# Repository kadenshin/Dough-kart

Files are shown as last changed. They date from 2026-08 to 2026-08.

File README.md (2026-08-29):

# Dough-kart


An easy-to-build, weldless drifting single-occupant electric go kart.\
I started this project on 7/22/2026. I just wanted to build something fun before I go off to college. I'm adding more features to this project as I think of them.
The design of the kart was heavily inspired from Razor's Crazy Cart XL.

## Design brief
- One rider 
- Rider height: 5’9 - 5’10, weight 140-160lb
- Electric powered 
  - Single powered wheel in the center-middle of kart
- Target top speed: ~ 20 mph
- Intended surface: pavement, concrete
  - Smooth surfaces only, little suspension
- Drift/drive method: two swivel caster wheels in the back and one steerable powered wheel near front always contacting ground
  - The casters' axis of rotation are able to be adjusted relative to the ground, which allows the rider to adjust level of "driftyness"
    - Caster wheels axis of rotation more oblique to the ground = more control 
    - Caster wheels axis of rotation perpendicular to the ground = Tokyo drift
- Maximum overall width and length: roughly 110cm x 70cm x 50cm
- Fabrication tools: soldering iron(optional), 3D printer, hacksaw, hand drill
- Estimated cost: ~$600 (half the price of the Razor Crazy Cart XL)

## Assembly
- The entire vehicle is weldless; everything is secured together with aluminum gussets and M8 bolts and nuts.
- There are jigs in the CAD folder to help with drilling accurate holes.  



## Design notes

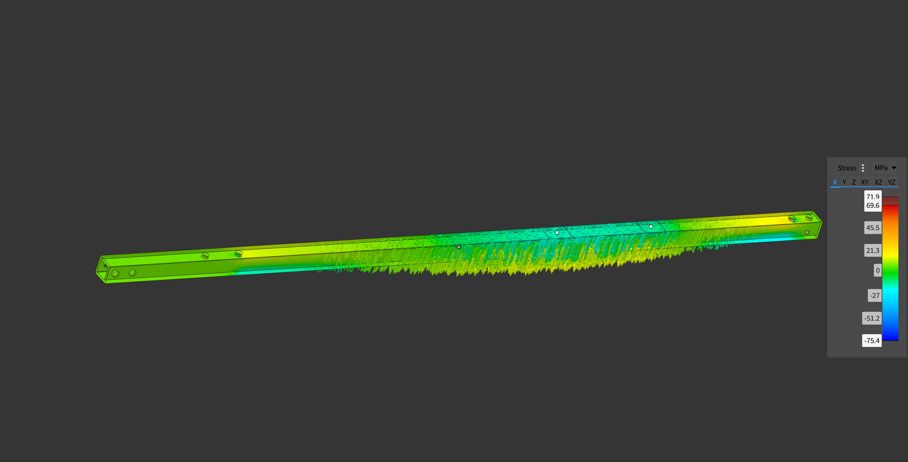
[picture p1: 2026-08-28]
assets/FrameFEA.png

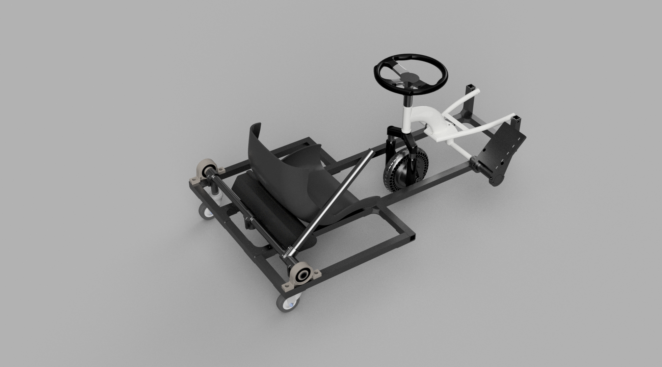
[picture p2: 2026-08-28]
assets/KartRENDER.png

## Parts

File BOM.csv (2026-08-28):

Item Name | Qty | Price (total) (USD) | Item link | Notes
Front Suspension Fork, 10 inch Shock Absorption Parts Anti Vibration Hydraulic Shock Absorber | 1 | $39.49 | Electric Scooter Front Suspension Fork, 10 inch Shock Absorption Parts Anti Vibration Hydraulic Shock Absorber | Suspension will hopefully dampen vibration (one of the biggest cons of a hub motor wheel)
Zip Ties 8 inch (100 Pack) | 100 | $3.99 | Zip Ties 8 inch (100 Pack), 40lbs Tensile Strength, Black Cable Ties, Wire Ties for indoor and outdoor use, by Skalon | Used for securing battery/electronics to frame
7/8" Inner Wide Round U Bolts | 2 | $8.19 | uxcell 7/8" Inner Wide Round U Bolts 2" Length 304 Stainless 2 Set | To secure the handlebar/footrest to the frame
Center punch | 2 | $5.68 | 2PCS Automatic Center Punch,5'' Spring Loaded Center Punch, Heavy Duty Steel Adjustable Center Marker Punch Tool with 2PCS Extra Replacement Tip for Metal,Plastic,Wood,Glass by YUIOASE | Essential for making accurate holes with a hand drill (I'm using jigs to align the center punch on the aluminum)
Polyureuthane Caster wheels | 4 | $12.98 | Caster Wheels with Threaded Stem, 3 Inch Locking Swivel Casters Set of 4 | For back wheels
Blue loctite/threadlocker | 1 | $7.49 | ThreadLocker Blue, Thread Lock Medium Strength Lock Tight for Nuts, Bolts, Fasteners and Metals, Anaerobic Curing Metal Glue to Prevent Loosening and Corrosion (M243-50ml) | For use on most bolts, there will be tons of vibration so threadlocker is needed to prevent loosening
M6 screw set | 1 | $9.99 | Fgruh 185PCS M6 Socket Screws Assortment Kit, M6x8/10/12/16/20/25/30/35 mm | For use on the pedal collars and screwing stuff onto the frame
3/8'-16 heatset inserts | 10 | $9.99 | ruthex 3/8"-16 Threaded Inserts - 15 Pieces RX-3/8“-16-x12.7 Brass Heat Set Insert for Plastic Parts - Inches UNC knurled Nuts - Insert by Heat into 3D Printing Components | For attaching the casters to the drifting assembly through the 3d printed adapter
1" pillow bearings | 2 | $15.79 | 2 Pack UCP205-16 Pillow Block Mounted Ball Bearing - 1" Bore - Solid Cast Iron Base - Self Aligning | For mounting the main back tube onto the frame
8in 36V 500W motor + controller + throttle | 1 | $139.90 | 8in Hub Motor Kit 36V 500W Brushless Gearless with 25A BLDC Controller | Very convenient as it comes with a controller and throttle
Li-ion 36v 10Ah battery | 1 | $0.00 |  | Already own an old one
Plexiglass sheets | 2 | $6.99 | 8×10" Plexiglass Sheets 1/8 inch Thick,3mm Clear Acrylic Sheet 2 Pack | Something for the electronics to sit on
XT60 connectors | 3 | $8.99 | Yeebline 3 Pairs (6PCS) XT60 Plug Female and Male Connector, XT60 Connector Plug Adapter with 100mm 12AWG Silicone Copper Wire Cable Cord for RC Lipo Battery Cable Drone | For connecting the battery to the motor controller
5 pin battery connector | 1 | $9.99 | KH866 E-Bike Battery Power Discharge Connector – Compatible with Hailong 5 Pin Connector Pair Male & Female Plug for Ebikes Battery, Cycling Parts, Black & Silver | For connecting the battery to the XT60 connector (need to solder)
Aluminum plates | 3 | $9.49 | PATIKIL 6061 T651 Aluminum Sheet Metal 6 x 8 x 1/25.4(0.04") Inch 3Pcs Flat Plain Aluminum Plate Covered Stock with Protective Film, Heat Rectangle 1MM for Lndustry Crafting | For shear panels to prevent the frame from racking
Foam tape | 1 | $5.35 | Frost King R734H Sponge Rubber Foam Tape 3/4" W X 7/16" H X 10' L, Black | To dampen the vibrations/impacts on the seat and the drift mechanism
1" pitch aluminum gussets | 18 | $74.09 | 1/2 in. Pitch Gussets — AndyMark | For securing the frame together
6061-T6 Aluminum tubes and 6063-T52square tubes | 15 | $158.24 | Speedy Metals 1" SQ x 3/4" ID x .125" Wall 6063 Aluminum Square Tube, https://www.speedymetals.com/pc-4590-8371-1-od-x-125-wall-tube-6061-t6-aluminum.aspx | For the frame, drift mechanism and drift lever.
Aluminum Slip-on Fitting(single socket tee | 4 | $38.64 | Aluminum Slip-on Fitting, Tee Through-Hole Connector for 1" Rail OD | McMaster-Carr | Single socket tees for attaching casters, drift lever and hardstop to the back tube. | NOTE: Shipping+taxes added to this part and below (classic McmasterCarr)
Tube-Connecting Nut (star nuts) | 5 | $14.24 | Tube-Connecting Nut, for 1.120" - 1.150" Tube ID, 3/8"-16 Thread Size | McMaster-Carr | For attaching the handlebar/footrest to the scooter headtube piece
M8 40mm socket screws | 50 | $20.26 | Black-Oxide Alloy Steel Socket Head Screw, M8 x 1.25 mm Thread Size, 40 mm Long, Partially Threaded | McMaster-Carr | For securing the frame together
M8 locknuts | 50 | $17.60 | High-Strength Steel Nylon-Insert Locknut, Zinc Plated, M8 x 1.25 mm Thread Size | McMaster-Carr | For securing the frame together
3/8"-16 bolts, washers, nuts | 10 | $14.53 | Grade 5 Steel Hex Head Screws with Nuts and Washers, Medium-Strength, 3/8"-16 Thread Size, 2" Long | McMaster-Carr | For securing the scooter headtube to the star nut
Total Price (USD): | $631.92

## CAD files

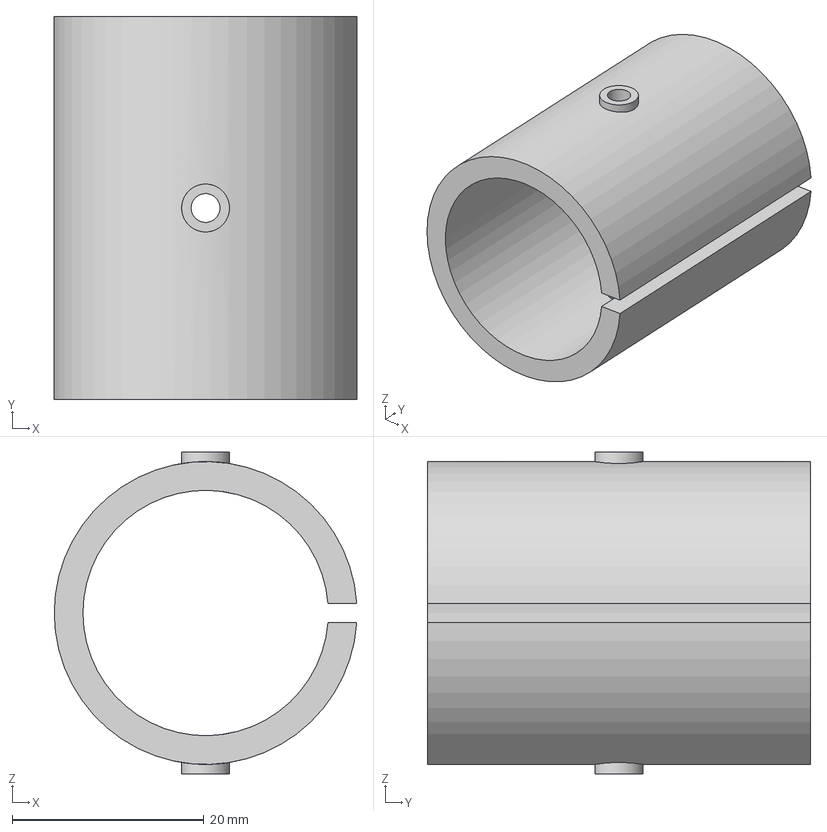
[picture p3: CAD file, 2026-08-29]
cad/Jig for round tubing.step
31.6 x 40.0 x 33.6 mm

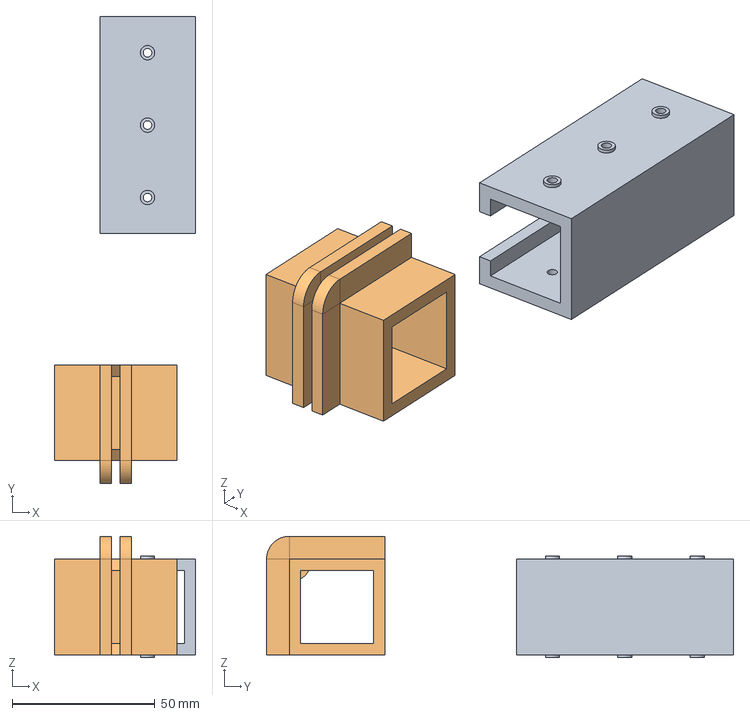
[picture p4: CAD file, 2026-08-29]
cad/Jigs for Sq. tubing.step
49.6 x 163.8 x 42.6 mm

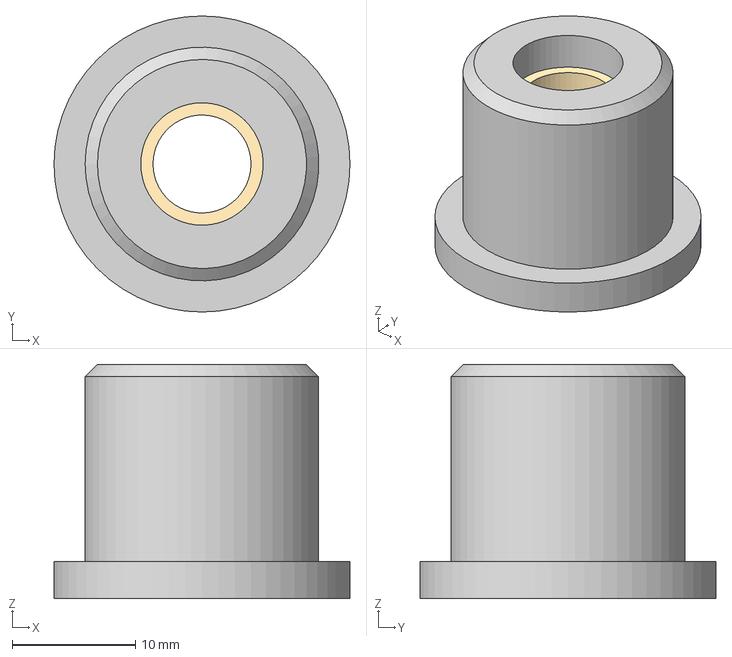
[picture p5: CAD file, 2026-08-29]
cad/3DP Insert for stem casters.step
24.0 x 24.0 x 19.0 mm

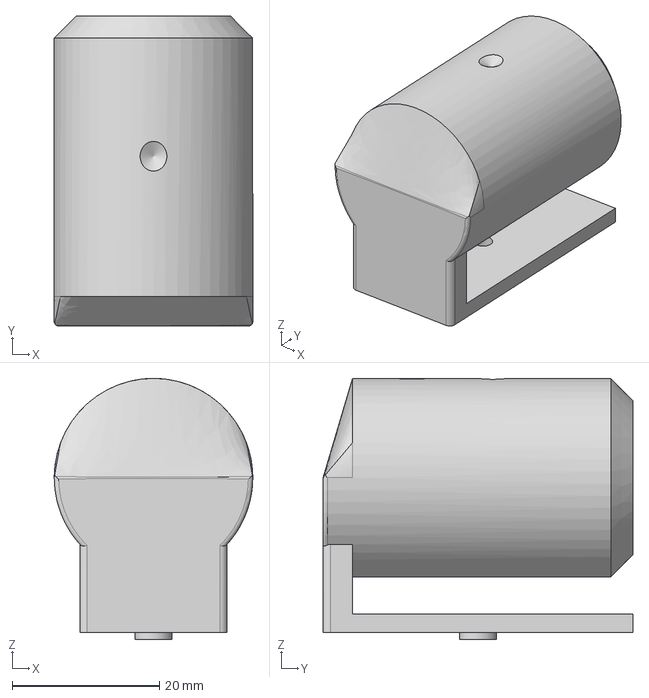
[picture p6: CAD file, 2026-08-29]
cad/Jig for SST.step
27.0 x 42.1 x 35.5 mm

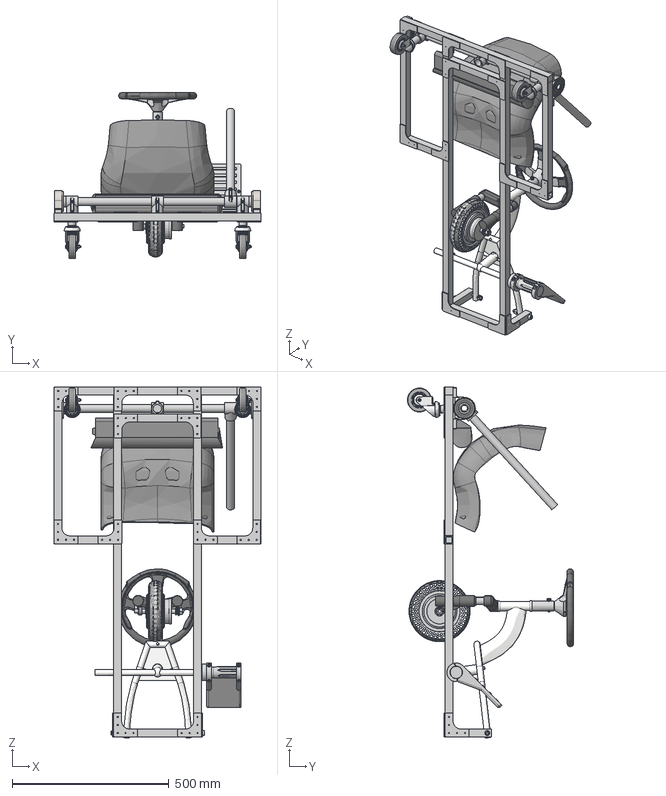
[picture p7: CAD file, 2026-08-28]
cad/KartFINAL.step
660.7 x 530.2 x 1120.4 mm
92217A617_18-8 Stainless Steel ASME Washer x 10
HFN ASME B18.2.4.4M - M14 x 2 Steel Grade 2H Plain x 2
ISO 4762 - M10 x 70 Steel 4.6 Plain
ISO 4762 - M10 x 70 Steel 4.6 Plain_1
ISO 10512 - M10 x 1.25 Steel 6 Plain x 2
ISO 10673-S-10 Steel 100 HV Plain x 3
94290A581_Tube-Connecting Nut
HSHCS ASME B18.3 - 1/4-20 UNC x 1 Steel Grade 2 Plain

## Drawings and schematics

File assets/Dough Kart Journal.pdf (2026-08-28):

# Dough Kurt

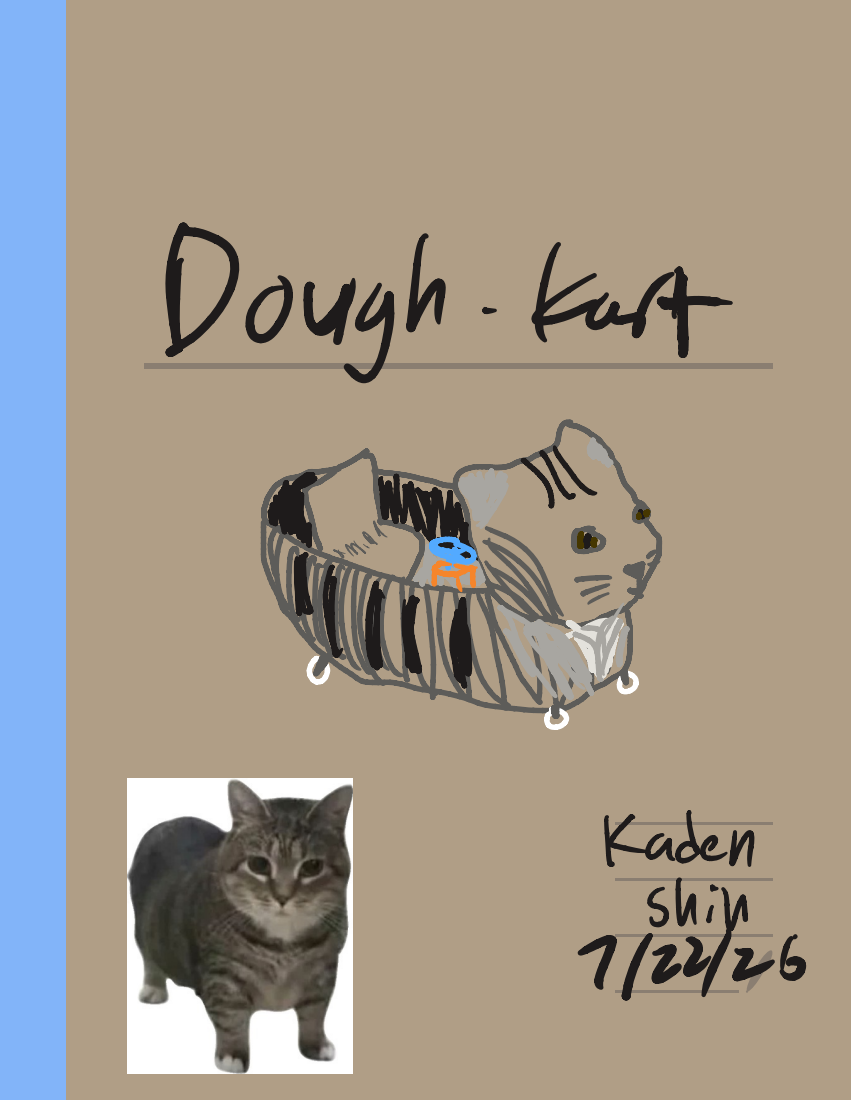
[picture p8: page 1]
Kaden Shill 1/22/26

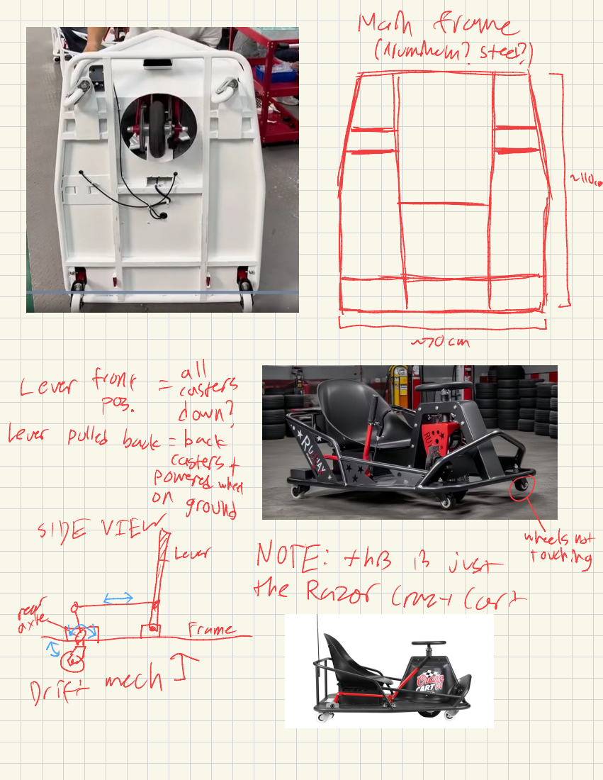
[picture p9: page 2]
Mach; frame; Lever; from e; -insters; POS.; down?; pulled back; = back; pastee; ground,; SIDE VIEW; heals; not; ame; NOTE:; thB; just; touching; the; Razor; Crust Cort; mech ⁻; Drift

## Potential add-ons:

## Timeline :

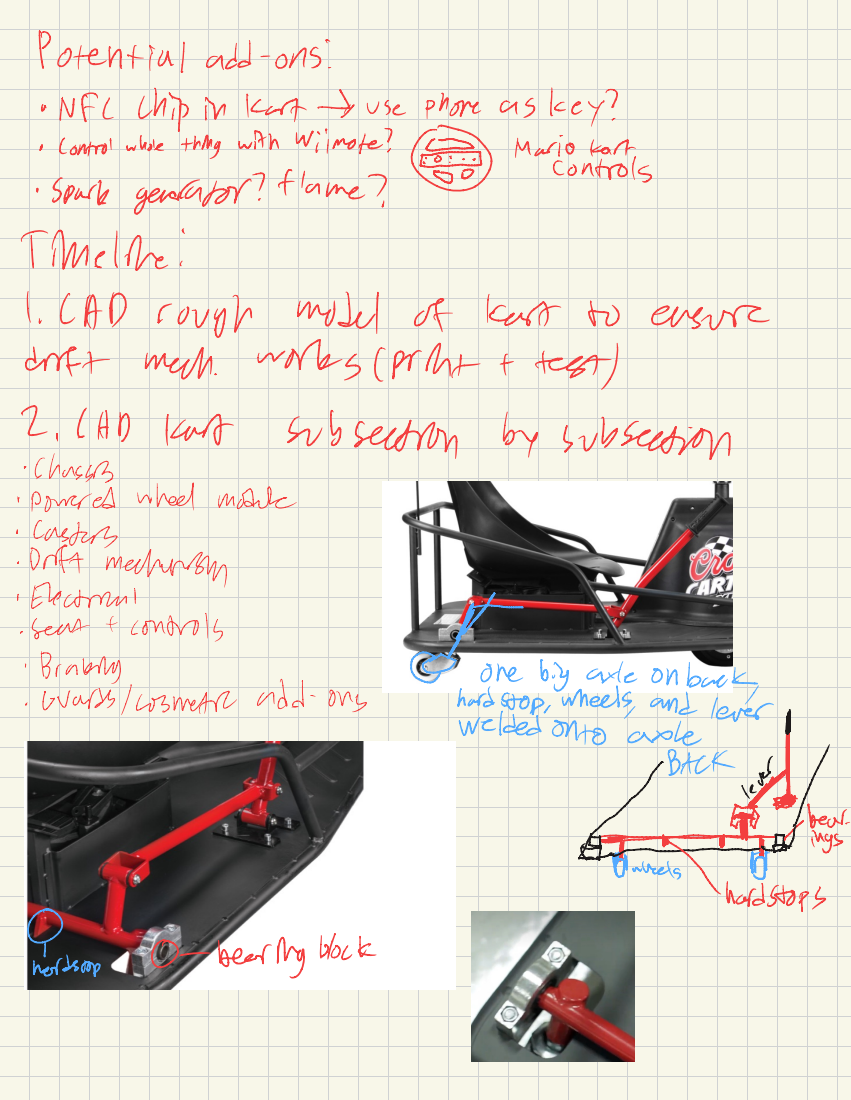
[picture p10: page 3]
NFLChip in; Kart -; use; phone as; key?; control; whole; thing; with Wilmote? D; Mario Kart; controls ·; spark; generator?; Flame?; LAD; rough; model; best; ensure; drift; mech.; Works (picht; + test; SHD; Kat; subsection; subsection ·; Shussig; powered; whed; module; Castel; Drift; mechan ·; Electricat; seat Brakiy; controls; one; big; axle on; back, ·; ovarss/cosmetic; add-ons; hardstop,wheels,ana; O wortstop; -bear ↑; O-bearing block

S. | Charly | drive
PROS | CONS

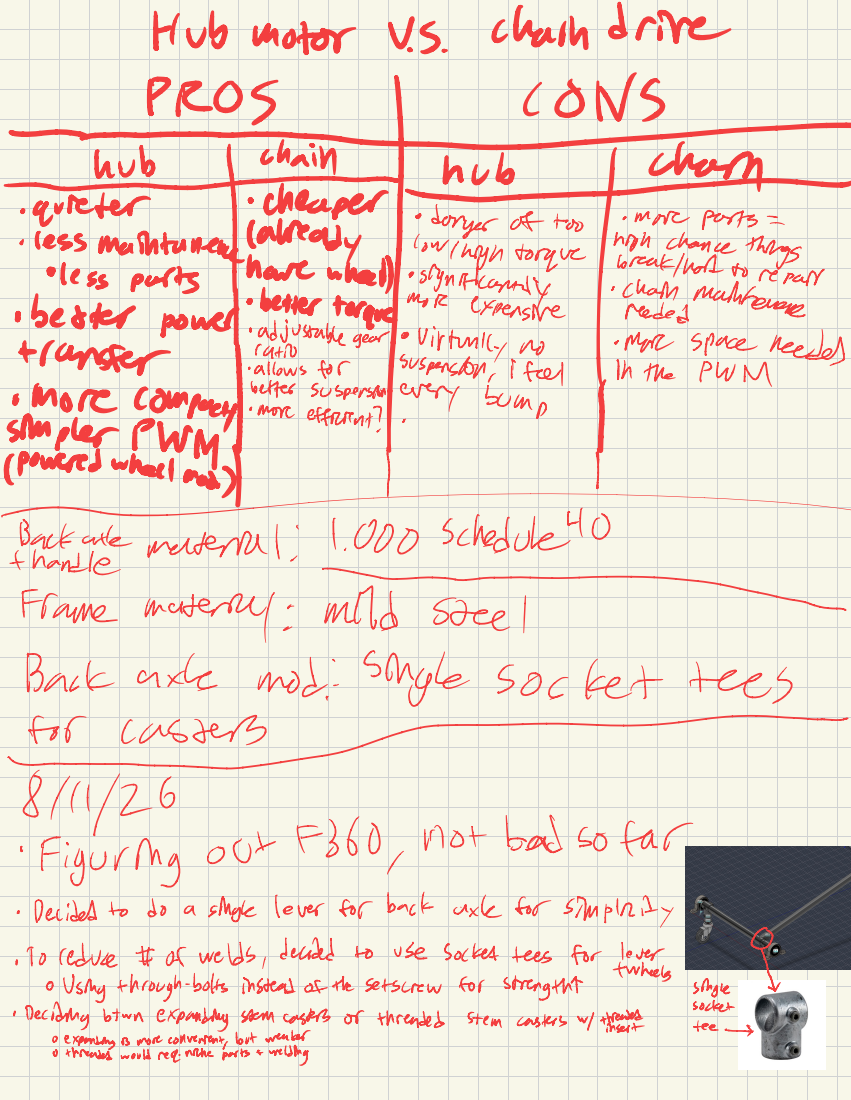
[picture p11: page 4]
motor; quieter; high; More ports =; chance things I; break/had to; repair ·; less; purts; significantly; Cham; expensive; Medesmaintenance; ransfer; more; space needed; for; suspension,; i feel; in the; PWM; better; suspension; every; morecompany me eara; somp; powered whe -; mod.; Backaxe materi :; Schedule o; > Frame; handle; material :; Mild; steal; Back; axle; mod:; Single; socket teas; casters; Figuring; our #360,; Decided to do; single; lever; back; axl; for simplicity; reduce; 9 walds ,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

not bab so far

Figz Figl ,
20

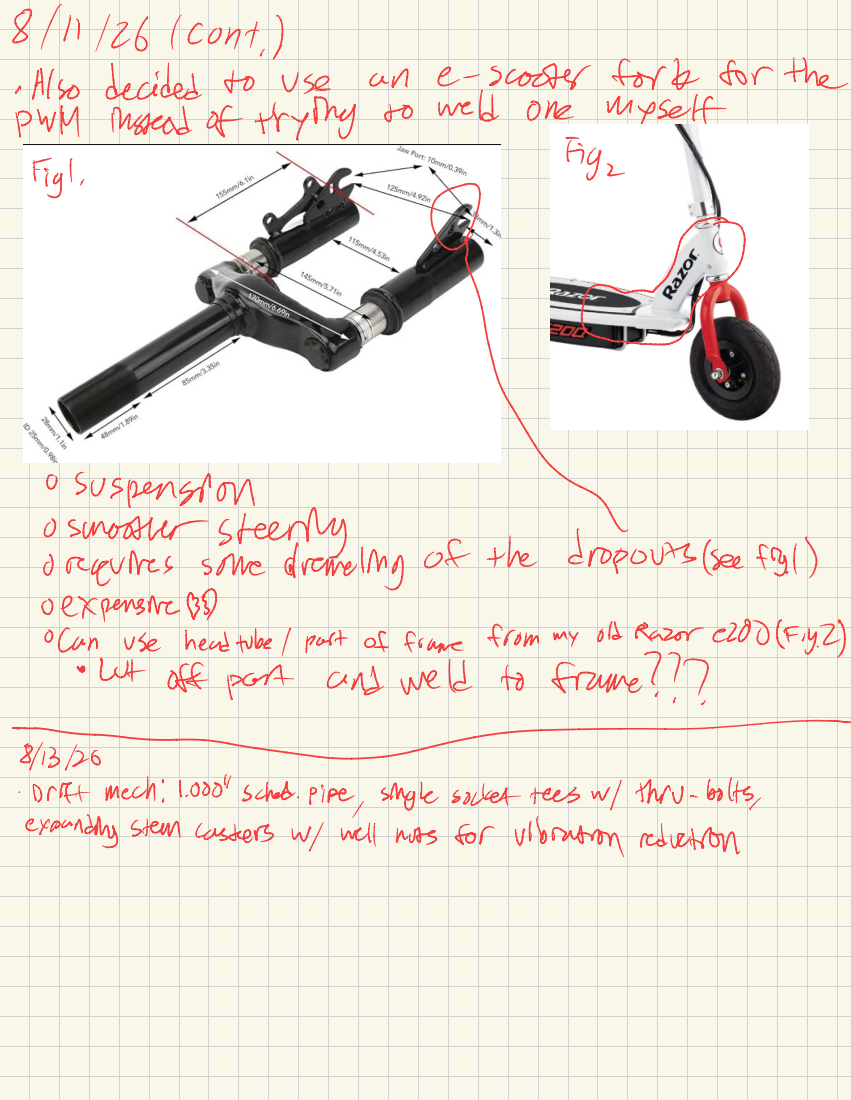
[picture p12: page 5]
(cont.; Also; decided; use; e-scooter; fork; for; the; PWM; instead of trying; weld; one; myself; smoother; steerily; suspension; requires; some; drawling; dropouts (see; fig.; expensive& ·; Can; headtibe/part; of frame; from; old; Razor 2300 (Fiy.; Lot; off; part; and; frame??7; Drift; mach :; sched.; Pipe, single; socket tees w/; thow-bolts,; expanding steal casters w/; well; nots; vibration; reduction

8)11/26 | Razer | E200 | dimensions

# TOP(M)

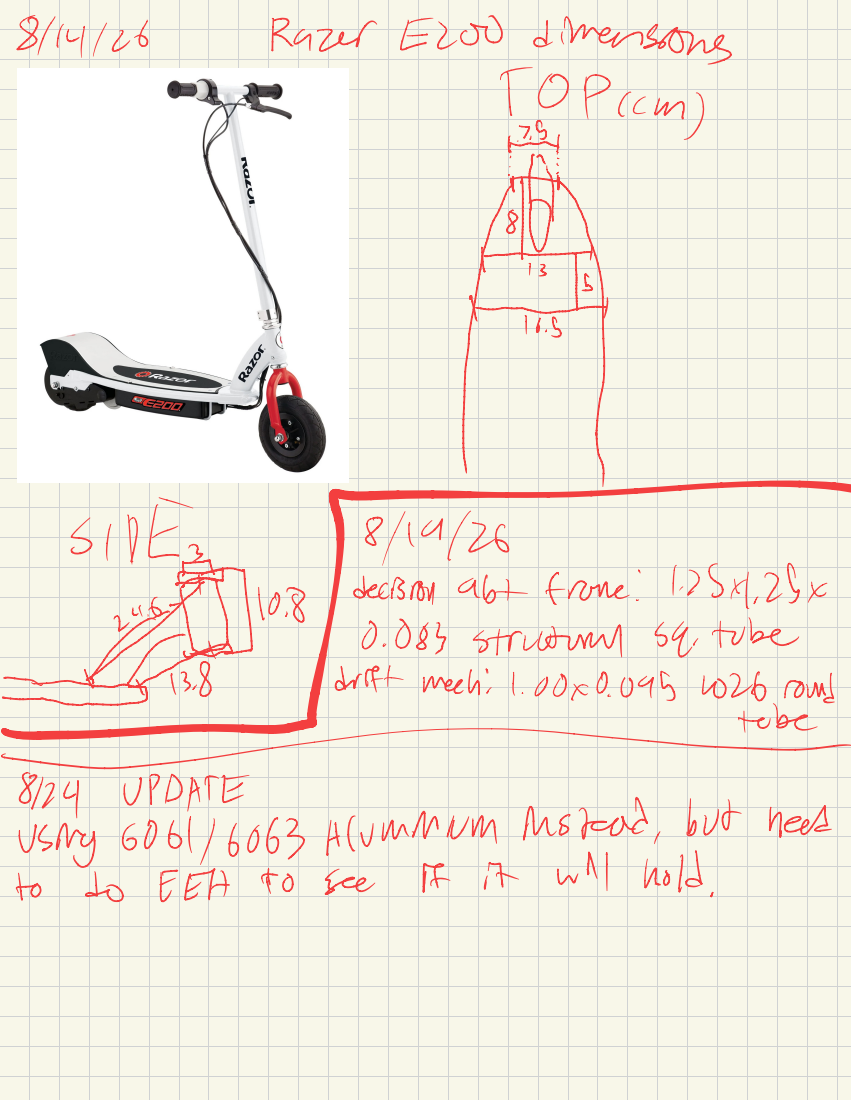
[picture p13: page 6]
SIDEs; decision; frame :; stiritual; tobe; drift; mech :; round; trbe; UPDATE; using; 6061/6063 Hlummum; instead ,; but; need; FEA; see; will; bold ,

SIDE | Load /sect
intwobeaside by | si

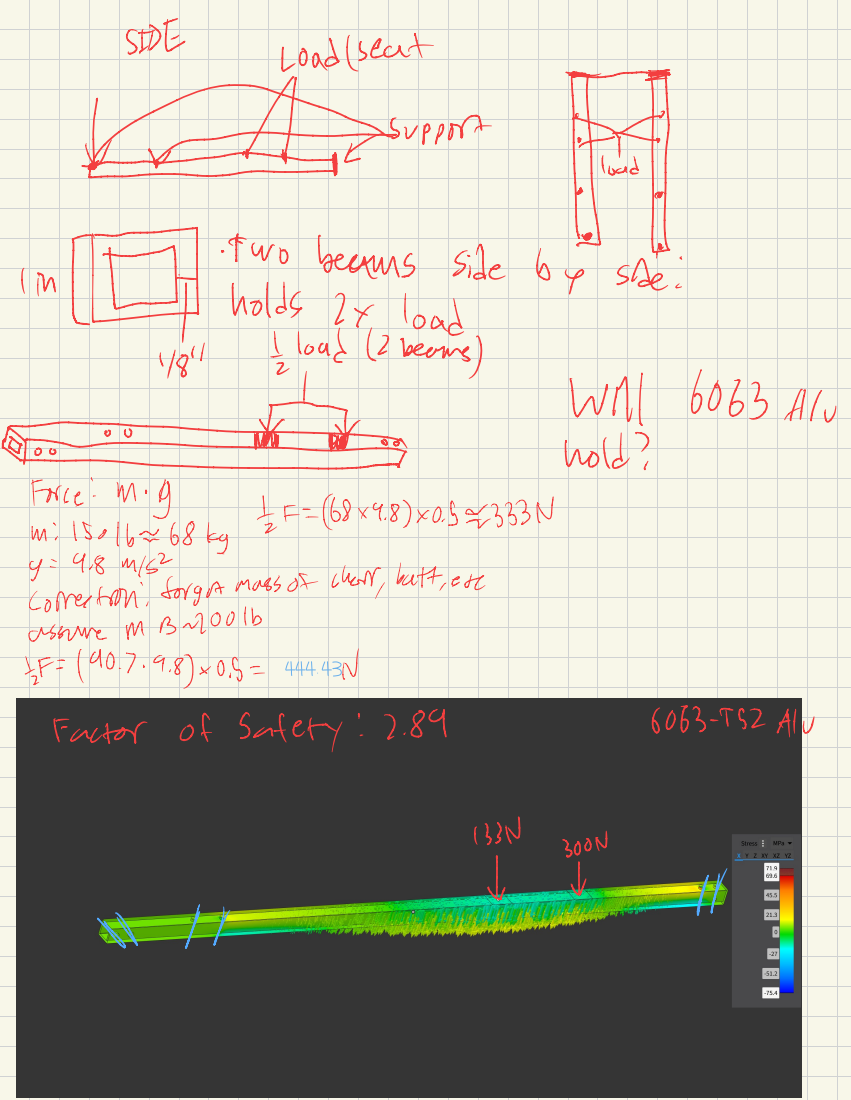
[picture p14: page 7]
# support; holds; loud; Will; Alr; hold?; Force: m .; Corres fro; forgot mass of; short,; butt,; assure; Factor; Ar Safety
